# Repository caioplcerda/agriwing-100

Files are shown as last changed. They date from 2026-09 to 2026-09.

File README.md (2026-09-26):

# AgriWing-100

**A 1-metre, fully 3D-printed flying wing that maps crops in RGB and near-infrared** for plant-health analysis on board, with a Raspberry Pi 5 and two Camera Module 3 units. Designed in Fusion 360, with aerodynamics checked in OpenFOAM, structure checked by hand analysis, and every part audited for assembly and support-free printing.

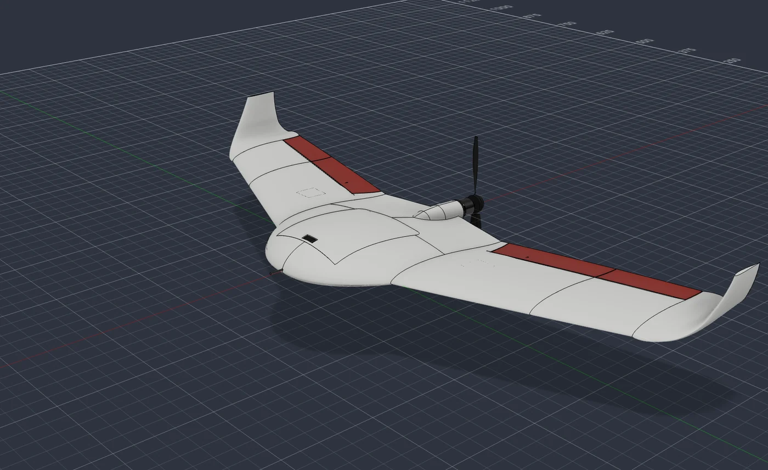
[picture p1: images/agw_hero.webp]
AgriWing-100 rendered in Fusion 360


**Full engineering dossier:** <https://caioplcerda.github.io/agriwing-100/>. It covers structure, wing and hinge, the assembly and print audit, CFD, mass and balance, build sequence and test plan.

| | |
|---|---|
| Configuration | Blended wing-body, MH60 reflex airfoil, 20° sweep, 7° washout, blended winglets, pusher prop |
| Size | 1.04 m span, 20 dm² class |
| All-up mass | 1234 g (376 g printed) |
| Cruise | L/D 12.4 (CFD, clean airframe), ≈15.5 m/s |
| Endurance | 55–78 min on a 3S2P Molicel P45B pack |
| Coverage | ≈110 ha per flight at 1.8 cm/px (60 m) |
| Printing | 17 parts, ~32 h, 256 × 256 mm bed, LW-ASA, no supports (a brim on 3 parts) |
| Parts cost | ≈ $536 |

## What Rev D fixed

Rev D applies what the [Dart-80](https://github.com/caioplcerda/dart-80) build taught. The same checks found eight faults in the previous revision, and all of them are fixed.

| Area | Before (Rev C) | Now (Rev D) |
|---|---|---|
| Wing bending across the body | Swept spars ending in the centre body; three M3 inserts on the belly carried the moment (SF ≈ 1.1) | Straight carry-through: Ø6 solid carbon joiner + 8×6 tube per wing (SF 3.2) |
| Wing panels | 0.6 mm shells with ribs | Solid models: the slicer sets walls and infill |
| Elevons | Jammed beyond ±10°; three ribs crossed the elevon; outer half undriven | Round-nose hinge, free to ±30°; Ø2 carbon torque rod couples both halves |
| Spar bore | Blocked inside W2 | Straight, verified end to end |
| Servos | Case 1.4 mm into the cover | Seated 2.4 mm higher |
| Hatch | Front edge free to lift | Hood and tongue lock the front edge |
| Control horn | Printed in foamed plastic | Bonded 1.5 mm G10 |
| Printing | 232 cm² of support under the hatch, bridges over 100 mm | Re-oriented and re-shaped: support-free |

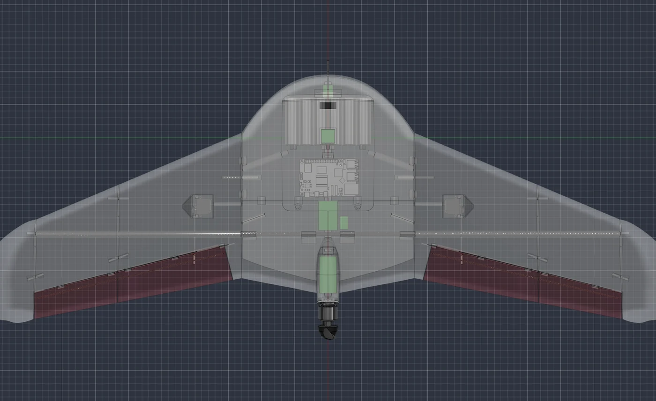
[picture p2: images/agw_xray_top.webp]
X-ray: straight carry-through spar
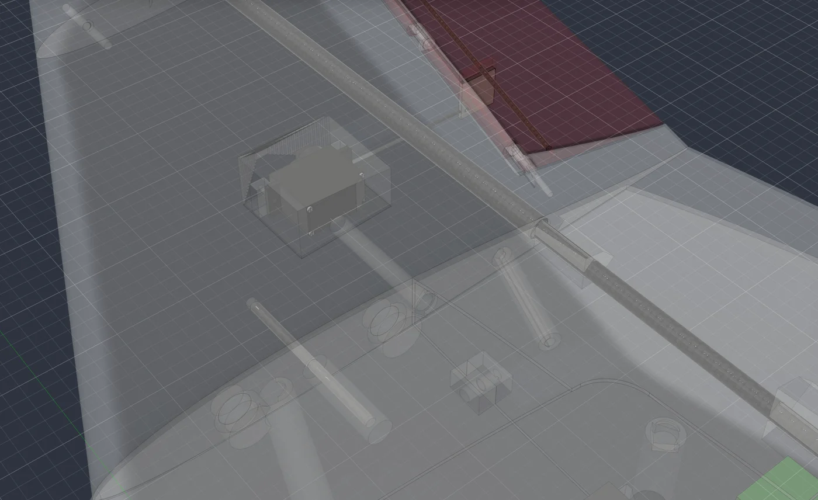
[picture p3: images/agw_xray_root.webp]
Root joint x-ray


### Hinge that actually moves
The elevon nose is now a cone around the hinge axis that turns inside a matching cove with 0.6 mm clearance. The printed knuckles take a Ø1.75 filament pin.

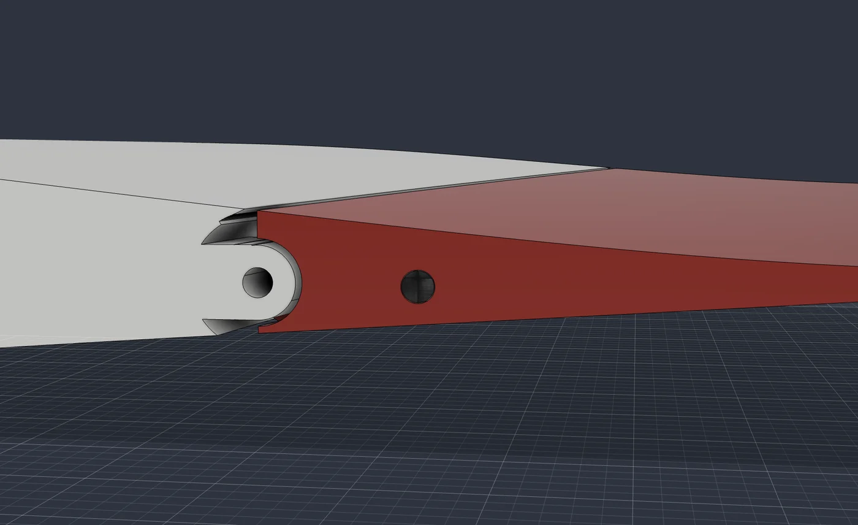
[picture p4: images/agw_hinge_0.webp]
Hinge section neutral
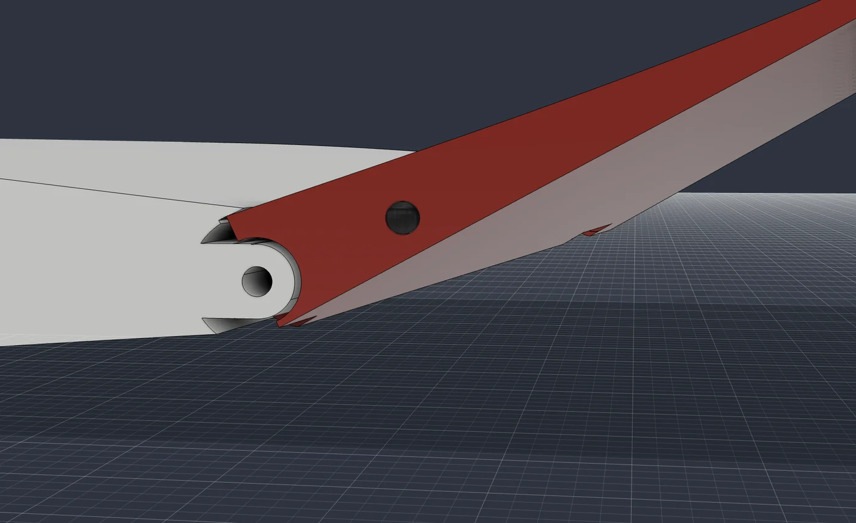
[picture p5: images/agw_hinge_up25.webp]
Hinge 25 degrees up
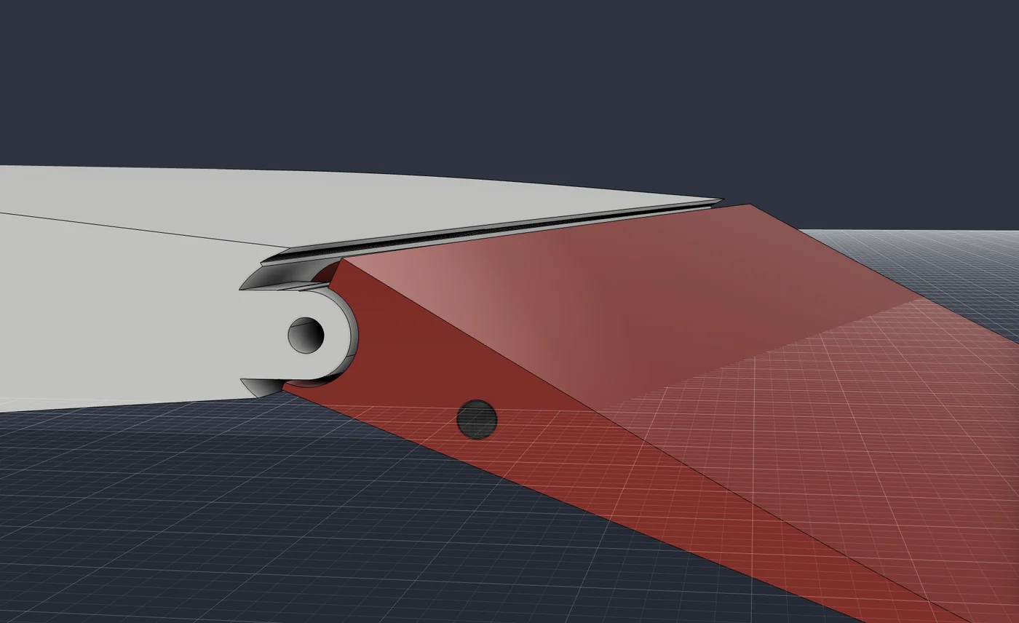
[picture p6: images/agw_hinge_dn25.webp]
Hinge 25 degrees down


### Every part checked for a way in, and for the printer
Each part was moved along the direction it actually has to travel and intersected with its neighbours. The wings go on in one straight spanwise move over the joiner, pin and magnets. For printing, each part got the best of ten candidate orientations, and any flat ceiling that remained was redesigned into a self-supporting shape.

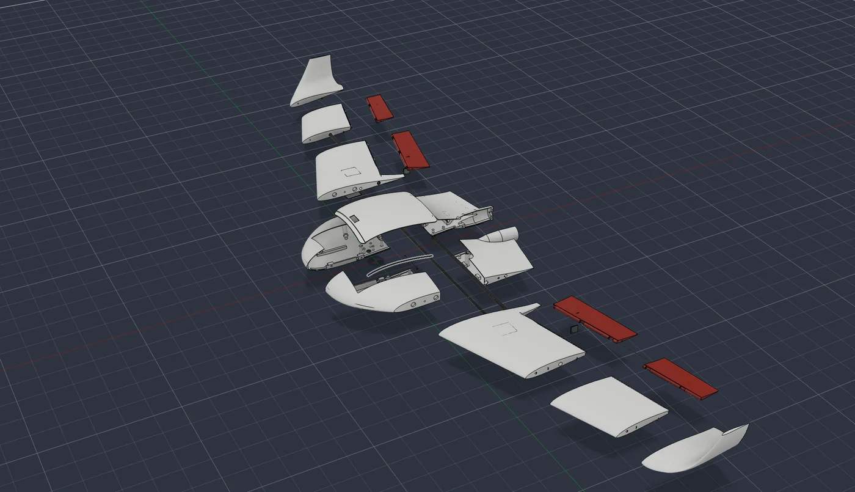
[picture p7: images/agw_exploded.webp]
Exploded assembly

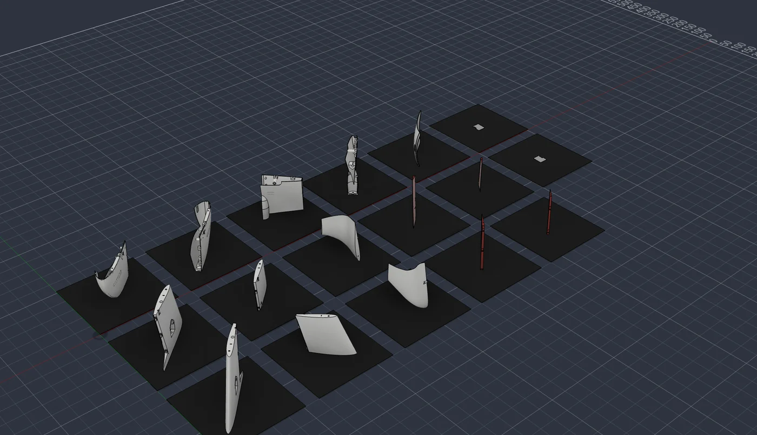
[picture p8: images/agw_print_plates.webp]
Parts on build plates
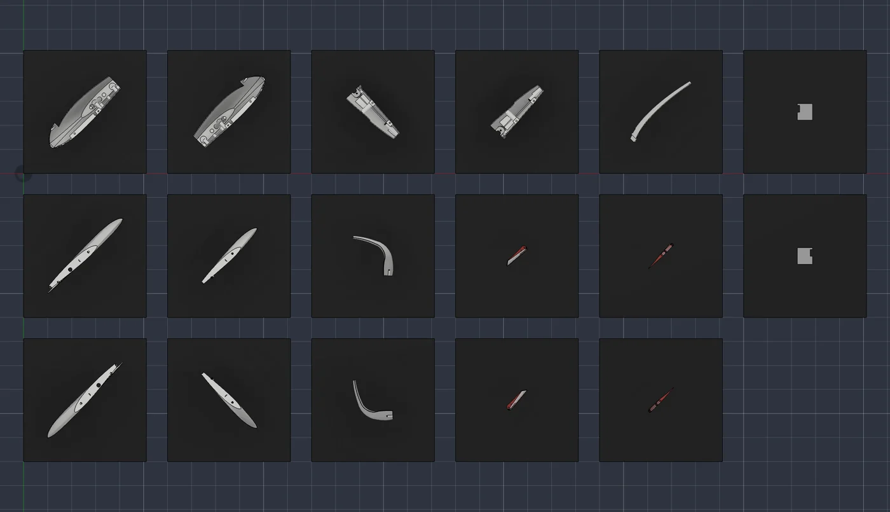
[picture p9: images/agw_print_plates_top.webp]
Build plates, plan view


### Aerodynamics
The CFD is a half-model RANS run in OpenFOAM (simpleFoam, k-ω SST, ≈0.8 M cells, 15 m/s).
- Lift is linear with CLα 0.071/deg.
- Neutral point at 83.3 mm, so the balance at 69.5 mm gives a 6.2% static margin.
- The blended winglet sheds one compact tip vortex, and drag is 4.6% lower than with plain fin winglets.

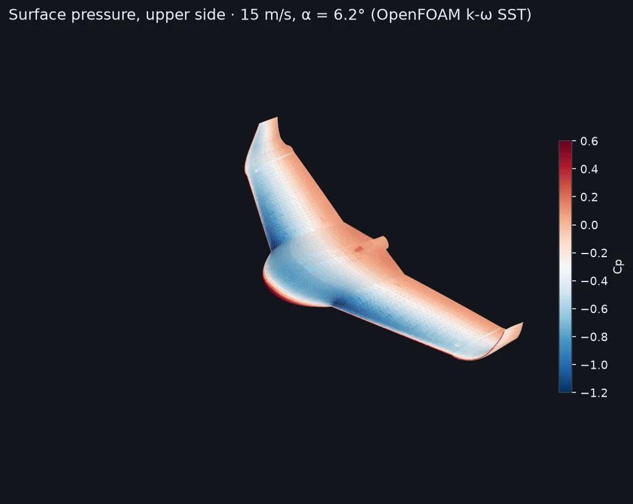
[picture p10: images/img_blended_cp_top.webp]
Upper surface pressure
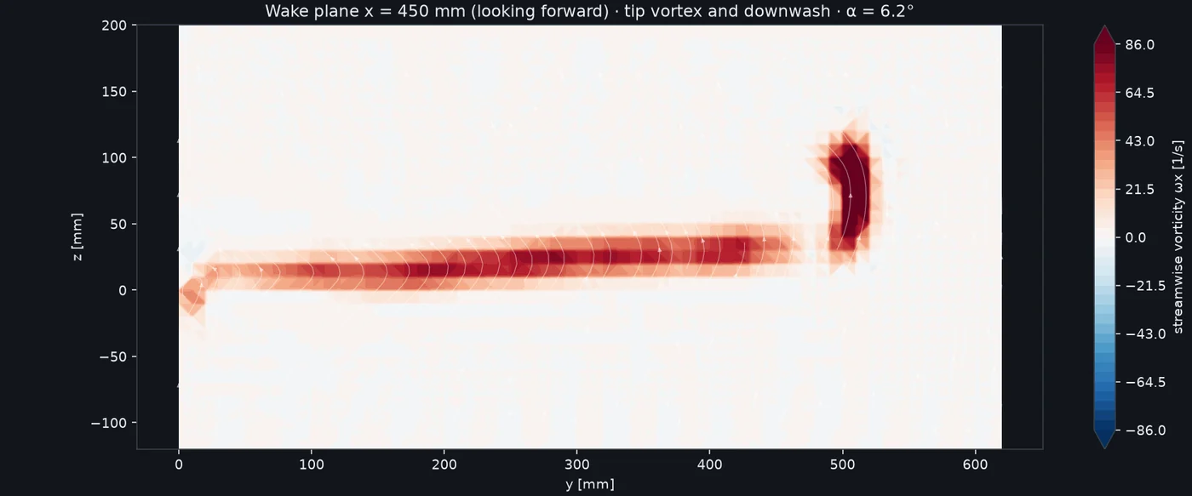
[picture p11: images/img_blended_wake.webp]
Wake behind the blended winglet

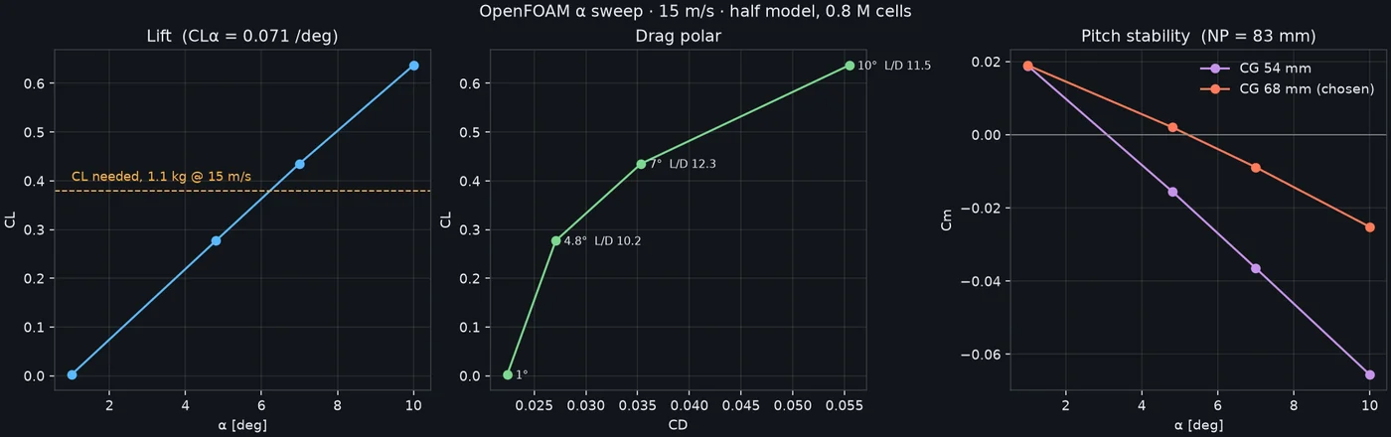
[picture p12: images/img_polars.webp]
CFD polars


## Gallery

| | |
|---|---|
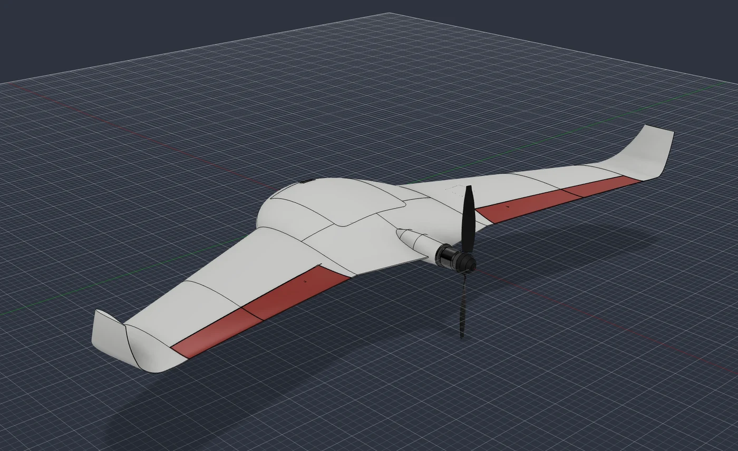
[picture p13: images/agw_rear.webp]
Rear
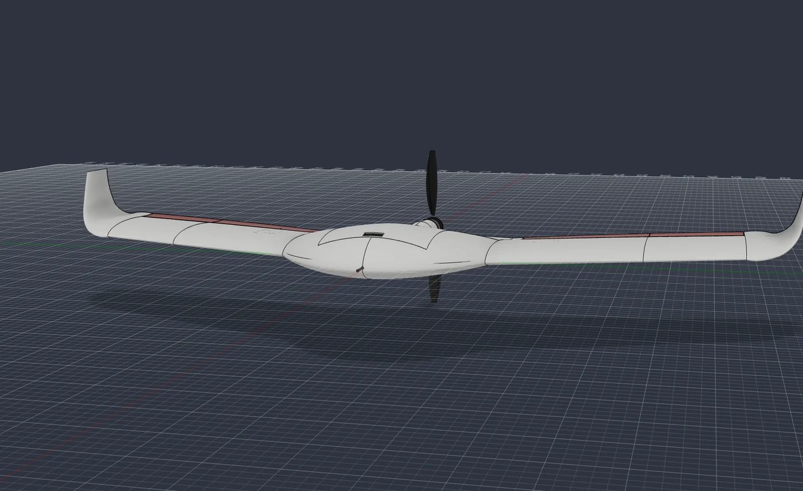
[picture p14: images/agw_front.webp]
Front
|  |  |
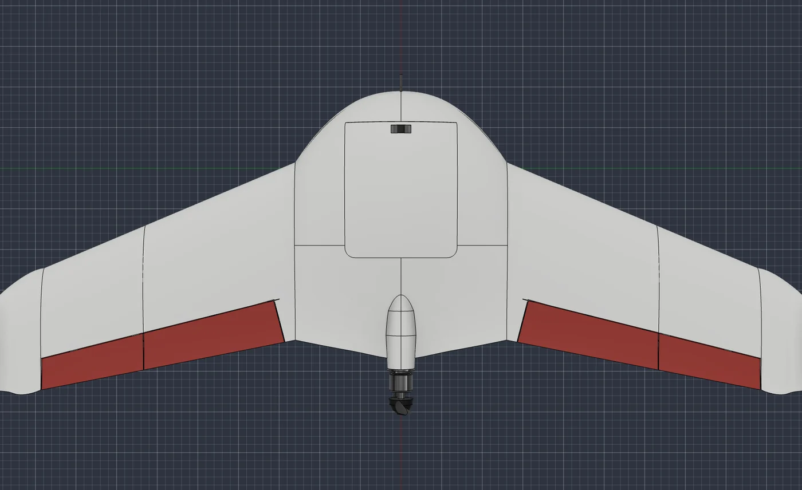
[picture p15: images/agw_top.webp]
Top
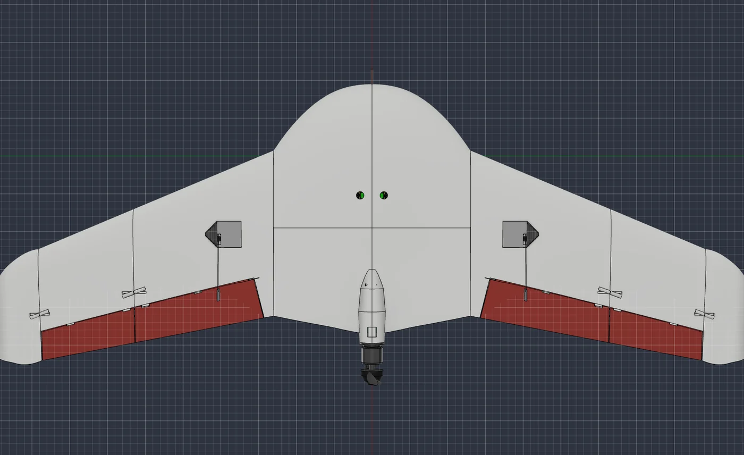
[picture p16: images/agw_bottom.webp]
Bottom
|  |  |
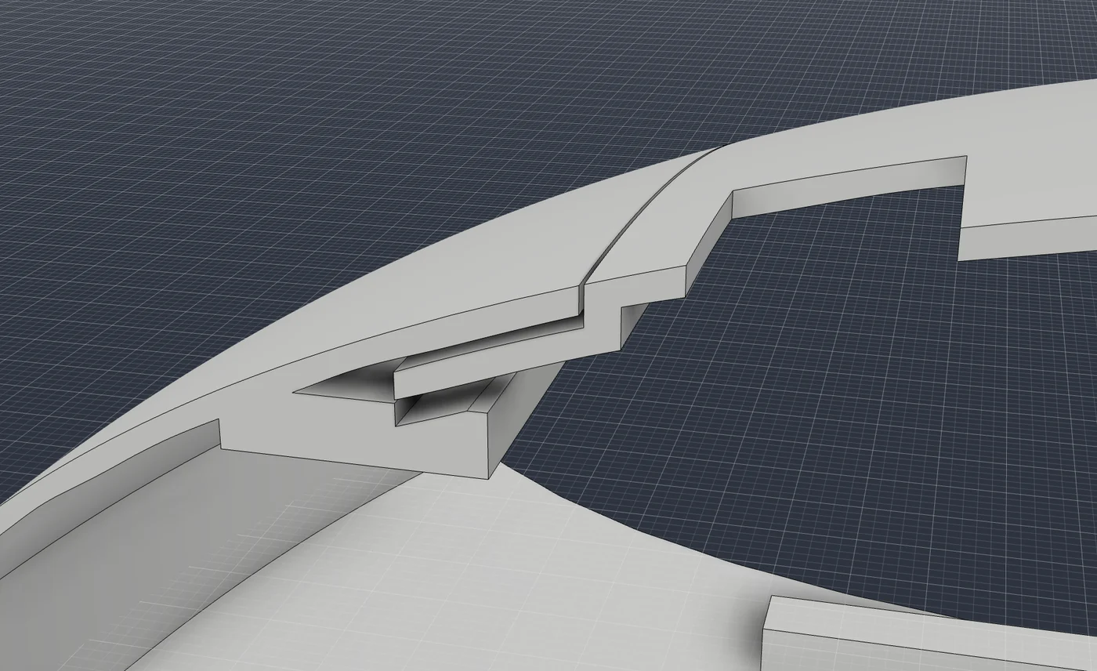
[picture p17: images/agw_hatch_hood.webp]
Hatch hood section
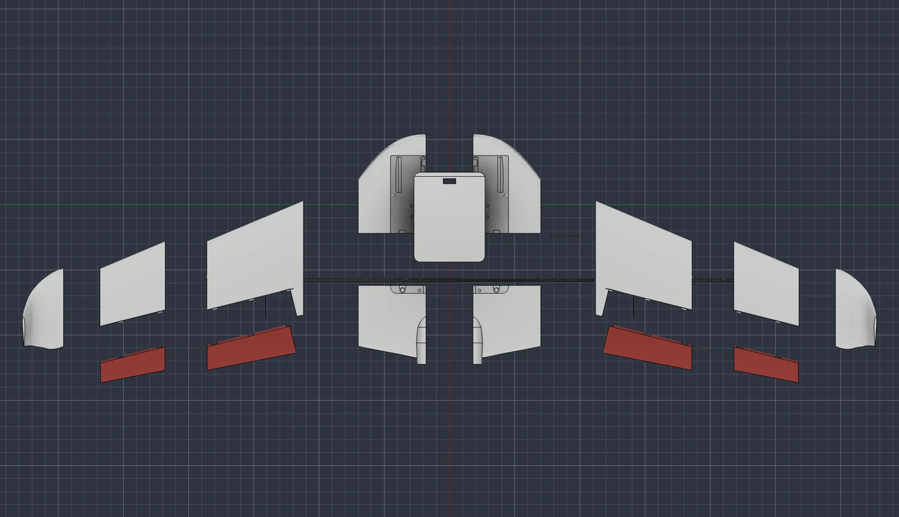
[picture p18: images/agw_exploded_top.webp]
Exploded plan
|  |  |

## Repository layout

```
cad/        AgriWing-100_RevD.step: assembly of this project's parts (printed + carbon + hardware envelopes)
stl/        17 print-ready STL files
docs/       the engineering dossier (served with GitHub Pages)
images/     renders and CFD images used here
analysis/   print plan, mass & balance, structural check, report builder, sizing and VLM trade studies
analysis/cfd/  OpenFOAM post-processing and the CFD summary
fusion/     Fusion 360 API scripts: Rev C build log and the Rev D rebuild (solid wings, hinge, joiner, print fixes)
tools/      helper to turn the dossier into a standalone page
```

## Build it

Quick references: [PRINTING.md](PRINTING.md) (per-part orientation, settings, time) and [BOM.md](BOM.md) (everything to buy). STLs as one zip: see [Releases](../../releases/latest).

1. **Print** the 17 STLs in LW-ASA (~0.6 g/cm³, enclosed printer) using the orientations in the dossier's *Print* section.
   - Wing parts: 2 walls, 6% gyroid.
   - Centre body and hatch: 3 walls, no infill.
2. **Buy** the parts:
   - Structure: Ø6 × 550 mm carbon rod, 2 × 8×6 carbon tubes (307 mm), Ø3 and Ø2 carbon rod, 1.5 mm G10 sheet, 10×3 N52 magnets, M3 heat-set inserts.
   - Electronics: Raspberry Pi 5, Camera Module 3 and NoIR, Matek H743-WLITE, M10Q GPS, ASPD-4525, SunnySky X2216, 40 A ESC, 2 × ES08MD II servos, 3S2P P45B pack.
3. **Assemble** as in the dossier's *Assembly* section: centre body and joiner first; then each wing (tube, W2, winglet, elevons, servo); then slide the wings on.
4. **Test** before flight:
   - Coupons.
   - A 4 g wing proof load.
   - Full ±25° elevon throw with both halves moving together.
   - A glide test at the design CG.

## Reproduce the analysis

```bash
python -m venv .venv && . .venv/bin/activate
pip install -r requirements.txt
cd analysis
python agw_mfg.py            # print plan: orientation, bed fit, overhang, mass, time
python agw_mass.py           # mass & balance, CG, static margin
python agw_struct.py         # structural checks at 6 g ultimate
python agw_build_report.py   # rebuilds the dossier into analysis/site/
```

## Third-party CAD

The Raspberry Pi 5, Camera Module 3, EMAX ES08A servo and 21700 cell models used for fit checks come from their manufacturers and [step.parts](https://www.step.parts). They are **not** redistributed here; download them from the original sources.

## Status and limits

- This is a design that has been analysed but **not flown yet**. The foamed LW-ASA allowables are assumptions until coupons are tested.
- The structural analysis is a hand beam-and-joint analysis, not FEM. The CFD is fully turbulent and has no propeller; plan on the lower endurance until a logged flight calibrates it.
- Fly within your local drone rules (weight class, altitude, line of sight) and with a failsafe configured.

## License

- Hardware design files (`cad/`, `stl/`, `docs/`, `images/`): **CERN-OHL-S v2** ([LICENSE](LICENSE)).
- Software (`analysis/`, `fusion/`, `tools/`): **MIT** ([LICENSE-MIT](LICENSE-MIT)).

See [LICENSING.md](LICENSING.md).

© 2026 Caio Lacerda

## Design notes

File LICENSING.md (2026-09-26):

# Licensing

This repository contains two kinds of material under two licenses.

| Material | Folders | License |
|---|---|---|
| Hardware design: CAD, STL, drawings, renders, documentation | `cad/`, `stl/`, `docs/`, `images/` | [CERN Open Hardware Licence v2, Strongly Reciprocal (CERN-OHL-S-2.0)](LICENSE) |
| Software: analysis and Fusion 360 scripts | `analysis/`, `fusion/`, `tools/` | [MIT](LICENSE-MIT) |

CERN-OHL-S lets you build, modify, sell and share the design, provided that modified designs you distribute are released under the same licence, with their source files.

Source location for CERN-OHL-S purposes: https://github.com/caioplcerda/agriwing-100

Third-party CAD used for fit checks during design (Raspberry Pi 5, Camera Module 3, servo and cell models) is **not** included; the assembly STEP contains only this project's own parts.

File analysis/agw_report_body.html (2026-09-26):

AgriWing-100 · 3D-printed mapping flying wing · structure, build & CFD dossier · Rev D

# AgriWing-100 Rev D

A 1-metre blended flying wing that maps crops in RGB and near-infrared for plant-health analysis. Rev D applies what the Dart-80 build taught: the wing bending now runs through a straight carbon carry-through instead of three belly bolts, every wing part is a solid model for the slicer, and every part was checked for a real way in and for support-free printing. That audit also found and fixed eight faults that were in Rev C.

All-up mass{{AUW}} g

Span1.04 m

Cruise L/D (CFD){{LD}}

Endurance @ {{VC}} m/s{{T_CONS}}–{{T_CFD}} min

Printed parts{{PARTS}} / {{PRINTED}} g

Parts cost${{COST}}

AgriWing-100 rendered in Fusion: white blended wing body with red elevons, blended winglets and a pusher propeller

Fusion model, Rev D. Red = elevons. Everything white is printed in LW-ASA.

Verdict

## What changed from Rev C, and why

Rev C looked finished. Checked the way the Dart-80 was checked, it had a weak wing joint, parts that could not move or be assembled, and parts that could not be printed as drawn. All of them are fixed in Rev D.

Area | Rev C | Rev D
Wing bending across the body | Two swept 6×4 tubes ending in the centre body; the moment crossed the y = 0 seam through 3 M3 inserts on the belly. SF ≈ 1.1 at ultimate. | Straight carry-through: Ø6 solid carbon joiner across the body, 8×6 tube in each wing. SF 3.2. The seam no longer carries wing bending.
Wing panels | 0.6 mm shells with ribs and sleeves. | Solid models; the slicer sets walls and infill (2 walls + 6% gyroid), with walls around every bore.
Elevons | Flat front face 0.5 mm behind the hinge: jammed beyond about ±10°. Three wing ribs ran through the elevon. Outer elevon had no drive at all. | Round nose in a cove (0.6 mm gap): free to ±30°. Ribs cleared. A Ø2 carbon torque rod couples both halves.
Spar path | Two thin slices inside W2 blocked the spar bore. | New straight bore, verified clear end to end.
Servos | Servo case 1.4 mm into its cover. | Servos seated 2.4 mm higher; screw holes, arms and pushrods follow.
Hatch | Front "tongue" only rested on a ledge; two rear magnets held the whole hatch against suction. | Front hood + tongue lock the front edge. Tilt the rear 4°, slide aft to open.
Control horn | Printed in foamed LW-ASA, a floating plate in the print. | 1.5 mm G10 horn bonded in a slot.
Printability | Hatch interior (232 cm²), winglet curve (60 cm²), centre-body root ribs (bridges over 100 mm) needed support. | Re-oriented and re-shaped: nothing needs support except a brim on three parts and a raft under the 0.8 mm servo covers.

Printed mass{{PRINTED}} g (Rev C 332)

All-up mass{{AUW}} g (Rev C 1152)

CG / static margin{{CG}} mm / {{SM}} %

Print time{{HOURS}} h

Structure

## A straight carry-through spar

At 6 g ultimate (4 g limit × 1.5) and {{AUW}} g, the Schrenk lift distribution puts {{M0}} N·m of bending on the centreline and {{M130}} N·m at the wing root. In Rev C that moment had to cross the centre body from one swept spar socket to the other, and the only tie across the y = 0 seam was three M3 inserts near the belly, all on the tension side with a 30 mm lever arm. That is the Dart-80's original mistake again, so it gets the Dart-80's fix: one straight load path.

- Joiner: Ø6 solid pultruded carbon rod, 550 mm, at x = 145 mm, z = 2.3 mm. It passes through the rear centre-body pieces on two 7 mm webs per side and slides 140 mm into each wing tube.
- Wing tube: 8×6 carbon, glued in W1 and W2 from the root to y = 438. The line was chosen where the thinnest section still leaves 1.6 mm of wall around the Ø8.1 bore.
- Torsion: the lift line is ahead of the spar at the root; a Ø3 carbon pin at x = 60 (85 mm ahead) takes the root torque, 0.13 N·m ultimate. The magnets only hold the wing on.
- Everything slides along y: joiner, pin, magnets and the new seam dowels all point spanwise, so a wing goes on and off in one straight move (the Dart-80 lesson about mixed directions).

{{FIG agw_xray_top | Top x-ray: the straight carbon line runs tip to tip at the same chordwise station through both wings and the centre body | Plan x-ray: joiner and wing tubes on one straight line; the servo bays, magnets and pins are visible.}} {{FIG agw_xray_root | Close x-ray of the wing root showing the wing tube, joiner, anti-rotation pin and magnet pockets | Root joint: 8×6 wing tube over the Ø6 joiner, Ø3 pin at x = 60, two magnets per side.}}

Check (ultimate) | Rev | Load | Allowable | Unit | Margin | Note

{{TBL_STRUCT}}

Allowables are conservative assumptions for foamed LW-ASA (0.6 g/cm³: 5 MPa across layers, 8 MPa bearing, 150 N per M3 insert) and datasheet values for carbon. Print the coupons listed under Test before flying.

Wing

## Solid wing parts and a hinge that moves

Each wing part is now the outer shape minus its functional voids only: tube and pin bores, seam dowels, magnet pockets, the servo bay, the lead channel and the hinge. The slicer puts two walls around every bore, so each carbon part sits in a printed sleeve tied to the skins by the infill. Printed at 2 walls and 6% gyroid, the solid W1 weighs about the same as Rev C's ribbed shell.

The elevon hinge was rebuilt. The elevon nose is a cone around the hinge axis at the local half-thickness (4.1 mm at the root, 2.7 at the tip), running in a matching cove with 0.6 mm clearance, and the wing lip was relieved wherever the elevon passes over ±32°. The printed knuckles and the Ø1.75 filament pin are kept. The inboard elevon end is cut square to the hinge axis, so the elevon slides off its knuckles and deflects without touching the wing root.

{{FIG agw_hinge_0 | Section through the hinge at y = 230: round elevon nose inside the wing cove, torque rod hole visible | Section at y = 230, neutral.}} {{FIG agw_hinge_up25 | Same section with the elevon 25 degrees trailing edge up | 25° up: the nose turns inside the cove.}} {{FIG agw_hinge_dn25 | Same section with the elevon 25 degrees trailing edge down | 25° down.}}

- Torque rod: Rev C had the horn on the inboard elevon only and the outboard elevon floating on the round pin. A Ø2 carbon rod at 80% chord now runs through both halves (bonded), so they move as one. The rod path keeps ≥0.9 mm of wall despite the 7° washout.
- G10 horn: 1.5 mm G10 in a 1.7 mm slot, pushrod geometry unchanged. Servo margin at 25 m/s with 20° elevon is 1.6 on an ES08MD II.
- Servo bay: servos seated 2.4 mm higher so the case clears the conformal cover; the bay end is a 45° stepped roof instead of a 35 mm bridge.

Audit

## Every part checked for a way in

Each part was moved along the direction it has to travel and intersected with its neighbours at several distances; any overlap means it cannot get there. Deflections were checked the same way by rotating the elevons about the hinge axis. All results below are zero intersection.

Joint / motion | Direction | Result
Wing unit off the centre body (joiner, pin, magnets) | +y, 0.3–160 mm | clear
W2 + winglet onto the W1 tube; winglet onto W2 | +y | clear
Joiner through the centre body | +y, 560 mm | clear
Elevons off their knuckles | square to hinge, 15 mm | clear
Elevon deflection, both sides, with horn | −30° … +30° | clear
Centre-body halves, front/rear pieces | ±y, ±x | clear
Hatch: locked front, tilt 4° and slide aft | +z blocked, then rotate + x | as designed
All printed parts vs. each other, hardware, cells, cameras, servos | at rest | no overlap

{{FIG agw_exploded | Exploded view of all printed parts and carbon parts along their assembly directions | Exploded along the real assembly directions: every wing part travels along y.}} {{FIG agw_exploded_top | Plan view of the exploded parts | Plan view of the same set.}}

Print

## Printability: support-free on a 256 mm bed

Every STL was put in its print orientation and searched for faces within 45° of horizontal facing down. Orientations were chosen per part by scoring ten candidates, then the geometry was changed where the best orientation still left a ceiling:

- Centre-body front pieces print root-rib down; the battery rails were thin fins that became floating plates, and now have 45° flanks that double as cell cradles.
- Rear pieces print motor-face down; the new joiner webs got a 45° V and the joiner bore a teardrop.
- Hatch stands on its side edge (1.3 cm² of overhang instead of 232 cm² dome-down).
- Winglets stand on the leading edge with a brim (4 cm² instead of 60 cm²).
- Joint faces of W2 and the winglet were made exactly planar so they sit flat on the bed.

{{FIG agw_print_plates | All printed parts on 256 mm plates in their print orientations | All parts in print orientation, one per plate.}} {{FIG agw_print_plates_top | Plan view of the build plates; every part stays inside its plate | Plan (orthographic): everything fits the 256 × 256 bed.}}

Part | Orientation | Height mm | Footprint mm | Support | Mass g | Hours

{{TBL_PRINT}}

### LW-ASA settings (Bambu, 0.4 nozzle)

Density

0.6 g/cm³ (foamed); calibrate flow with a 20 mm cube

Wing parts

Solid models: 2 walls, 3 top/bottom, 6% gyroid

Centre body, hatch

Modelled thin-walled: 3 walls, infill off

Enclosure

Closed, 45–50 °C chamber for ASA

### Centre body details

- Hatch front locked by a hood and tongue (below); two magnets at the rear.
- 10 mm centreline keel doubler inside the belly, between the camera windows, for belly landings.
- Battery centroid at x = {{XBATT}} mm, 6.8 mm forward of Rev C to keep the balance; the airspeed sensor sets the forward limit.
- Receiver moved beside the flight controller, off the joiner line.

{{FIG agw_hatch_hood | Section through the hatch front showing the hood of the centre body over the hatch tongue | Hatch front: the centre-body hood overlaps the hatch tongue, 0.2 mm clearance.}}

CFD

## Aerodynamics (OpenFOAM, Rev C geometry)

The outer shape did not change in Rev D except for the hinge details, so the Rev C CFD still applies: simpleFoam, k-ω SST, half model, ≈0.8 M cells, 15 m/s. Neutral point x = {{NP}} mm; with CG {{CG}} mm the static margin is {{SM}}% and the wing needs almost no elevon reflex at cruise.

α | CL | CD | L/D | Cm @ x=54

{{TBL_POLAR}}

{{FIG img_blended_cp_top | Upper surface pressure coefficient at cruise | Upper-surface Cp at cruise.}} {{FIG img_blended_wake | Wake plane behind the blended winglet showing a single compact tip vortex | Wake behind the blended winglet: one compact tip vortex.}}

{{FIG img_polars | Lift, drag and pitching moment polars from the CFD alpha sweep | α sweep: linear lift, Cm crossing zero near cruise.}}

Mass

## Mass, balance and performance

Item | g | x mm | $

{{TBL_MASS}}

Cruise power (CFD drag){{P_CFD}} W

Cruise power (conservative){{P_CONS}} W

Endurance{{T_CONS}}–{{T_CFD}} min

Stall{{VS}} m/s

Performance is the Rev C CFD result scaled to Rev D weight at the same lift coefficient (power ∝ W^1.5). Plan on the lower endurance until a logged flight calibrates it.

Assembly

## Assembly sequence

Centre body

1. Halves. Bolt CB_FrontRight to CB_FrontLeft and CB_RearRight to CB_RearLeft (M3 into heat-set inserts), then front to rear.
2. Joiner. Push the Ø6 × 550 mm carbon rod through the rear pieces from one root rib to the other so 140 mm sticks out each side. Glue the Ø3 anti-rotation pins into the front pieces at x = 60.
3. Electronics. Battery on the rail cradles against the forward stop, Pi 5 on its standoffs, cameras on the belly windows, FC, receiver beside it, ESC aft. Hatch: tongue under the hood, lower the rear onto the magnets.

Wings (each side)

4. Tube into W1. Epoxy the 8×6 tube into W1 from the root so it ends flush at the root face.
5. W2, then winglet. Slide W2 onto the tube with the two Ø3 dowels (all along y) and epoxy the joint face; same for the winglet at y = 440.
6. Elevons. Bond the Ø2 torque rod through both elevon halves, glue the G10 horn in its slot, seat the elevons on the knuckles square to the hinge line, push the Ø1.75 filament pin in from the tip.
7. Servo. Seat the servo on its lugs (M2), arm through the slot, 1.2 mm Z-bend pushrod to the horn, cover on.
8. Mount. Slide the wing onto the joiner and pin until the magnets pull it home.

Test

## Before the first flight

- Coupons: print three 10×10×80 LW-ASA bars standing up and snap them across the layers; they must hold ≥5 MPa. Pull-test one M3 heat-set insert in a printed block; it must hold ≥150 N.
- Proof load: support the centre body, load each wing to 4 g (≈24 N, 60% inboard of y = 300). No creak, full recovery.
- Controls: full throw ±25° without binding, both halves of each elevon move together, zero free play.
- CG: x = {{CG}} mm, measured aft of the root quarter-chord point (x = 0 in the CAD, 95 mm behind the nose). Glide-test before powered flight.

Limits of this analysis

- Hand analysis of beams and joints, not FEM. Foamed LW-ASA allowables are assumptions until the coupons are tested.
- CFD is the Rev C geometry (fully turbulent, no propeller). The hinge-gap changes of Rev D are not modelled.
- Vendor models (Raspberry Pi 5, Camera Module 3, EMAX servo, 21700 cells) are used for fit checks only and are not redistributed.

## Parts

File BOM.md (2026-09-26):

# Bill of materials: AgriWing-100 Rev D

Prices in USD per line (2026 typical). Masses and positions feed the balance model in `analysis/agw_mass.py`. Radio transmitter and charger not included.

| Item | Mass g | x mm | Line cost |
|---|---:|---:|---:|
| Centerbody, 4 printed pieces (LW-ASA) | 143.5 | 83.1 | $14 |
| Hatch (LW-ASA) | 19.0 | 21.1 | $2 |
| Wing W1 x2 (solid, 2 walls + 6 % gyroid) | 95.4 | 99.2 | $8 |
| Wing W2 x2 (solid) | 48.8 | 153.3 | $4 |
| Blended winglets x2 (solid) | 33.4 | 198.0 | $2 |
| Elevon 1 x2 (solid, round nose) | 21.4 | 197.5 | $2 |
| Elevon 2 x2 (solid, round nose) | 13.4 | 231.1 | $1 |
| Servo covers x2 | 1.0 | 103.1 | $0 |
| Carbon joiner rod O6 solid, 550 mm | 24.1 | 145.0 | $9 |
| Carbon wing tubes 8x6, 2 x 307 mm | 20.9 | 145.0 | $10 |
| Carbon elevon torque rods O2, 2 x 280 mm | 2.8 | 207.4 | $3 |
| Carbon anti-rotation pins O3 (2) + seam dowels O3 (8) | 4.7 | 150.0 | $4 |
| G10 control horns 1.5 mm (2) | 2.0 | 183.4 | $3 |
| PETG filament hinge pins 1.75 mm (2) | 1.0 | 200.0 | $0 |
| Magnets 10x3 N52 (8) | 14.4 | 60.0 | $6 |
| M3 bolts + heat-set inserts (7), M2.5/M2 inserts, grommets | 16.0 | 70.0 | $8 |
| Servo EMAX ES08MD II (2) | 26.0 | 103.9 | $20 |
| Servo arms + 1.2 mm pushrods (2) | 3.0 | 130.0 | $3 |
| Raspberry Pi 5 4 GB + heatsink + SD | 56.0 | 60.0 | $75 |
| Camera Module 3 + NoIR (+720 nm LP) + cables | 16.0 | 52.5 | $65 |
| Matek H743-WLITE | 22.0 | 117.0 | $70 |
| ELRS receiver | 5.0 | 128.0 | $15 |
| Matek M10Q-5883 GPS | 8.0 | 0.0 | $30 |
| ASPD-4525 + pitot + tubing | 7.0 | -75.0 | $40 |
| ESC 40 A | 25.0 | 205.5 | $20 |
| SunnySky X2216 1100 KV + cross mount | 73.0 | 261.0 | $30 |
| Folding prop 9x6 + spinner + adapter | 18.0 | 288.0 | $12 |
| BEC 5 V 5 A, wiring, XT30 | 60.0 | 40.0 | $25 |
| Epoxy / CA (joints, tubes) | 8.0 | 120.0 | $0 |
| Li-ion 3S2P Molicel P45B flat + BMS | 445.0 | -23.9 | $55 |
| **Total** | **1234** | **CG 69.5** | **$536** |

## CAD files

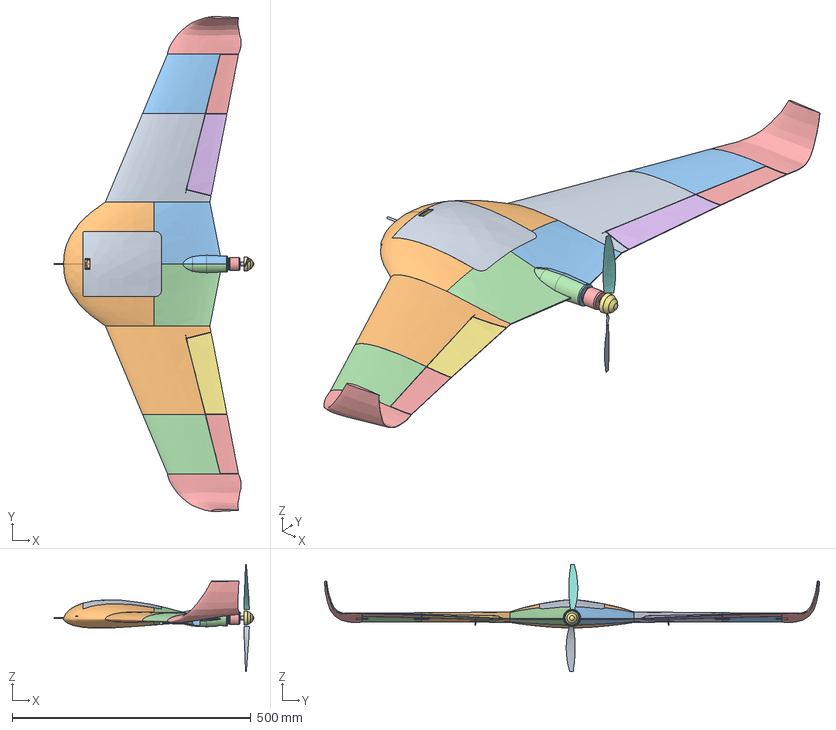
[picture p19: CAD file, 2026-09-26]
cad/AgriWing-100_RevD.step
419.0 x 1037.4 x 224.6 mm
Centerbody (1)
Wing
Hardware (1)

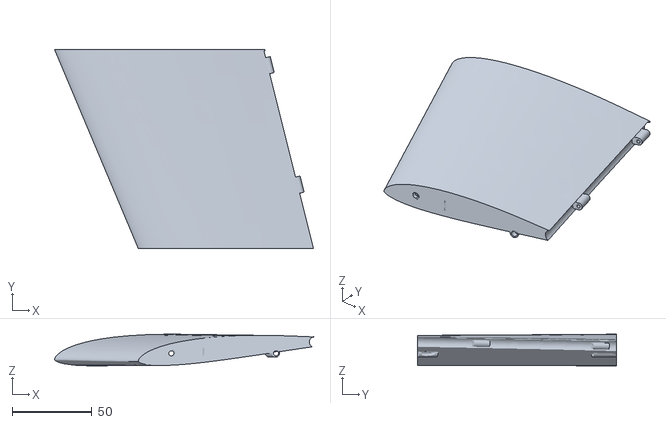
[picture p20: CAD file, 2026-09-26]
stl/W2_L.stl
162.6 x 125.0 x 19.9

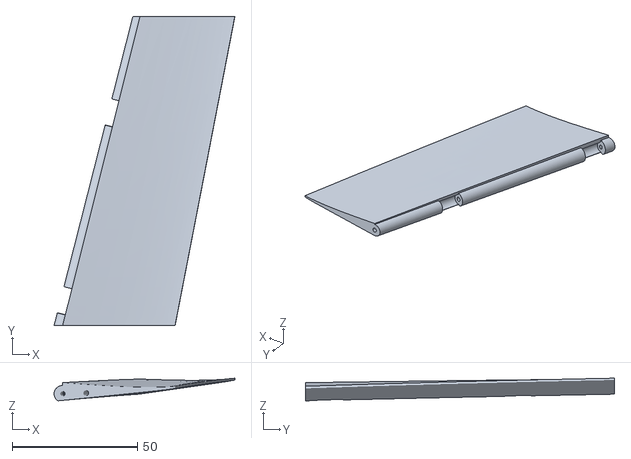
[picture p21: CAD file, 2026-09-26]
stl/Elevon2_R.stl
72.2 x 123.3 x 9.06

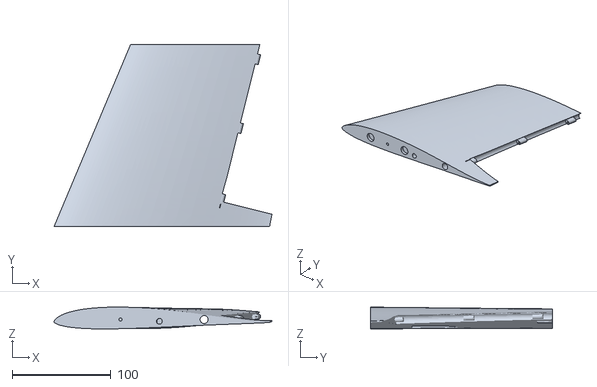
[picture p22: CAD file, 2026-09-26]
stl/W1_R.stl
221.3 x 185.0 x 22.2

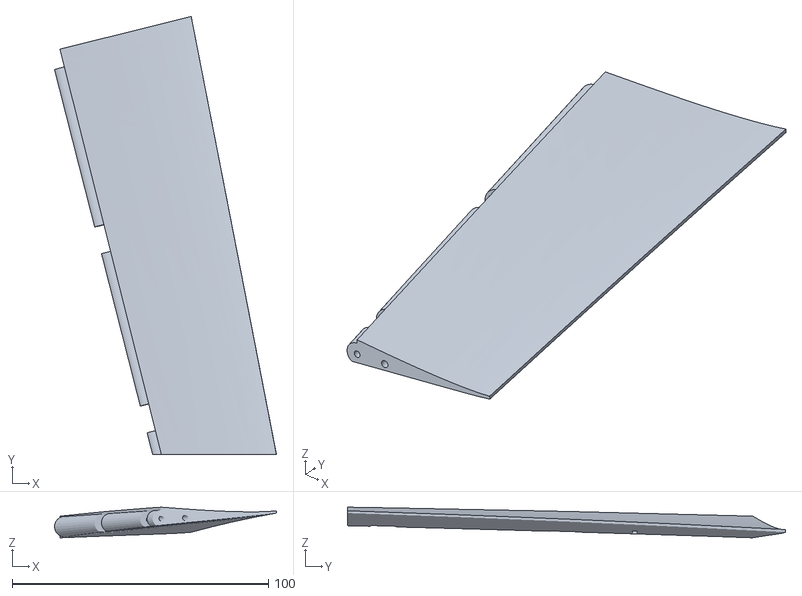
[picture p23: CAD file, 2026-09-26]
stl/Elevon1_L.stl
86.7 x 171.0 x 12.0

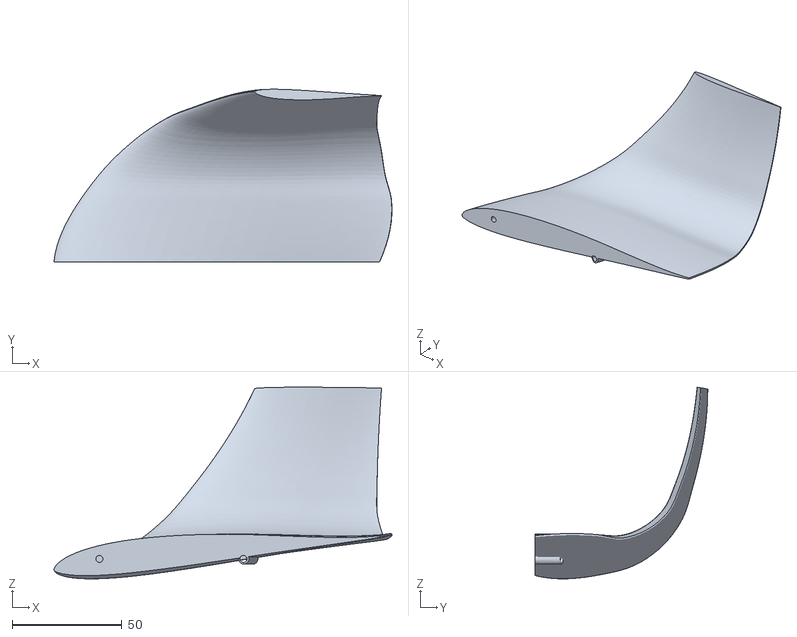
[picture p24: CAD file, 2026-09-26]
stl/WingletBlend_R.stl
154.3 x 78.8 x 87.5

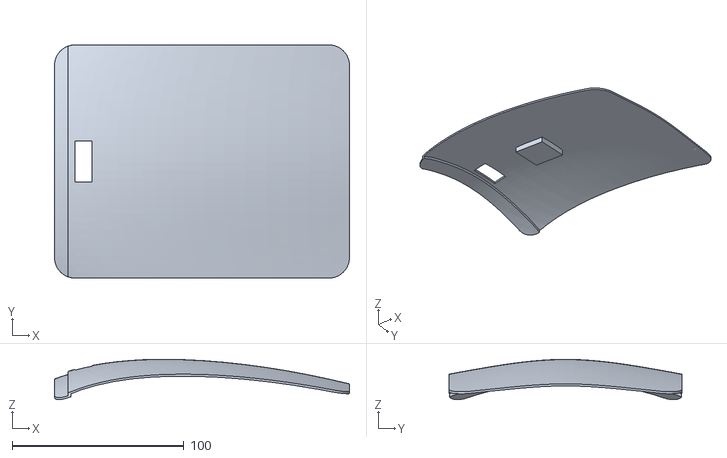
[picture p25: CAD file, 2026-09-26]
stl/Hatch.stl
172.0 x 136.0 x 23.5

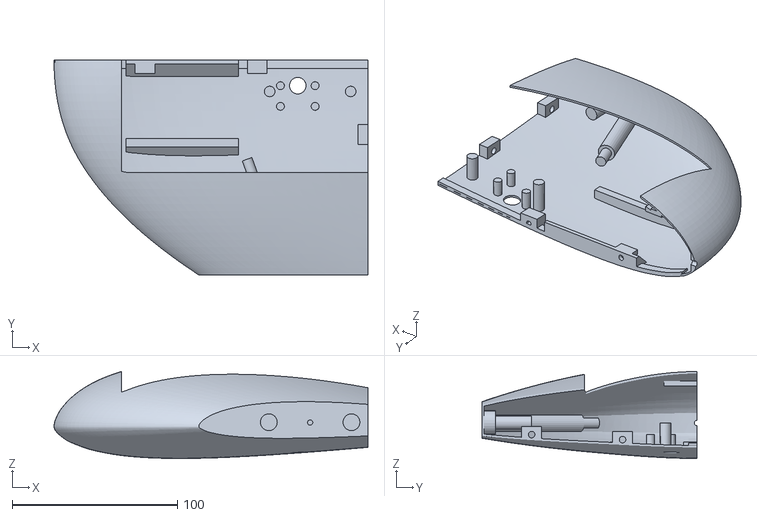
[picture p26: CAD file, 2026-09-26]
stl/CB_FrontLeft.stl
190.0 x 130.0 x 52.7

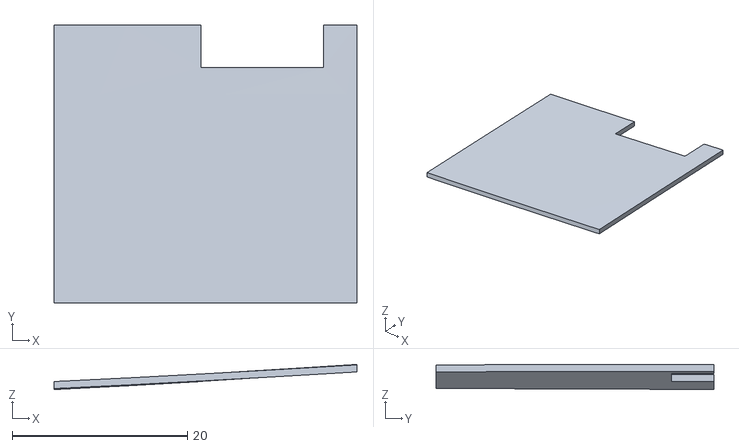
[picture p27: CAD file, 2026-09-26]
stl/ServoCover_R.stl
34.6 x 31.8 x 2.88

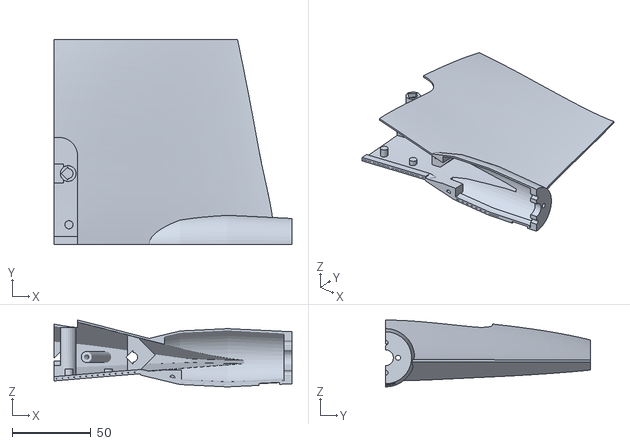
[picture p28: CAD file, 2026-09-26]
stl/CB_RearRight.stl
151.0 x 130.0 x 42.4

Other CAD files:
stl/W1_L.stl
stl/Elevon1_R.stl
stl/CB_RearLeft.stl
stl/WingletBlend_L.stl
stl/CB_FrontRight.stl
stl/Elevon2_L.stl
stl/W2_R.stl
stl/ServoCover_L.stl

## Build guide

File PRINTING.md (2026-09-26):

# Printing guide: AgriWing-100 Rev D

Enclosed printer (ASA), 256 × 256 mm bed, 0.4 mm nozzle. Nothing needs support; three parts take a brim, and the 0.8 mm servo covers take a 2-layer raft.

| Part | Orientation | Height mm | Support | Mass g | Hours |
|---|---|---:|---|---:|---:|
| `CB_FrontLeft` | root-rib face (y = 130) on the bed | 130 | none | 37 | 3.0 |
| `CB_FrontRight` | root-rib face (y = 130) on the bed | 130 | none | 37 | 3.0 |
| `CB_RearLeft` | motor face (x = 246) on the bed | 151 | none | 35 | 2.8 |
| `CB_RearRight` | motor face (x = 246) on the bed | 151 | none | 35 | 2.8 |
| `Elevon1_L` | standing on the inboard end (square to the hinge) | 174 | none | 11 | 1.0 |
| `Elevon1_R` | standing on the inboard end (square to the hinge) | 174 | none | 11 | 1.0 |
| `Elevon2_L` | standing on the inboard end | 123 | none | 7 | 0.7 |
| `Elevon2_R` | standing on the inboard end | 123 | none | 7 | 0.7 |
| `Hatch` | standing on its left edge, brim | 136 | brim | 19 | 1.7 |
| `ServoCover_L` | outer face up | 3 | 2-layer raft | 0 | 0.3 |
| `ServoCover_R` | outer face up | 3 | 2-layer raft | 0 | 0.3 |
| `W1_L` | standing on the root face | 185 | none | 48 | 3.8 |
| `W1_R` | standing on the root face | 185 | none | 48 | 3.8 |
| `W2_L` | standing on the y = 315 joint face | 125 | none | 24 | 2.1 |
| `W2_R` | standing on the y = 315 joint face | 125 | none | 24 | 2.1 |
| `WingletBlend_L` | standing on its leading edge, brim | 154 | brim | 17 | 1.5 |
| `WingletBlend_R` | standing on its leading edge, brim | 154 | brim | 17 | 1.5 |
| **Total (17 parts)** | | | | **376** | **32.1** |

## Slicer settings (LW-ASA)

| Setting | Value |
|---|---|
| Target density | ≈0.6 g/cm³ foamed; calibrate flow and temperature with a 20 mm cube |
| Wing parts (W1, W2, winglets, elevons) | solid models: 2 walls, 3 top/bottom, 6 % gyroid |
| Centre body, hatch, servo covers | modelled thin-walled: 3 walls, infill off |
| Chamber | closed, 45–50 °C |

## After printing

- Horizontal bores are teardrops (peak up in print); ream the round part and fill the peak with thickened epoxy on assembly.
- Heat-set M3 inserts: centre-body seams and the motor mount. M2 pilot holes in the servo lugs.
- Glue the G10 horns into their slots and the 8×6 tube into W1 before joining W2.

The same data drive `analysis/agw_mfg.py`; re-run it after changing any STL.

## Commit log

2026-09-26 feat: AgriWing-100 Rev D, 3D-printed crop-mapping flying wing
    Complete design release: STEP assembly (own parts only), 17 print-ready
    STLs, engineering dossier (carry-through structure, solid wings,
    round-nose elevon hinge, assembly and print audit, CFD, mass and
    balance, build and test plan), analysis scripts and Fusion 360 API
    scripts. Hardware under CERN-OHL-S v2, software under MIT.
    [AgriWing-100_RevD.step, CB_FrontLeft.stl, CB_FrontRight.stl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]
2026-09-26 docs: add printing guide and bill of materials
